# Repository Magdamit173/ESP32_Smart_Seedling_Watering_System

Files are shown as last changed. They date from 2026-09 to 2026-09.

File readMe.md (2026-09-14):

# ESP32-Based Smart Seedling Watering System with Automated Environmental Control

A low-cost, locally controlled seedling watering prototype designed to reduce repetitive manual watering while combining embedded programming, environmental sensing, real-time scheduling, relay/solenoid control, fluid delivery, and mechanical fabrication.

> **Project:** Midterm Project #1  
> **Course:** Microprocessors, Microcontroller Systems and Design  
> **Author:** Rovic B. Magdamit  
> **Institution:** University of Caloocan City – College of Engineering

## Overview

The system automates watering for a small seedling tray using an **ESP32-C3** as the central controller. It uses a **DHT22/AM2302** for temperature and relative-humidity monitoring and a **DS3231 RTC** for the time reference required by daily watering schedules.

A phone or laptop connects directly to the ESP32's local Wi-Fi access point and opens the controller's web interface. No cloud service or external router is required.

The final prototype uses a gravity-fed water path:

```text
~10-L Reservoir
      │
      ▼
 Clear Tubing
      │
      ▼
 Solenoid Valve
      │
      ▼
 Water Outlet
      │
      ▼
 Seedling Tray
```

The electrical/control path is:

```text
DHT22 ───────────────┐
                     │
DS3231 ──────────────┤
                     ▼
                ESP32-C3
                     │
              Control Logic
                     │
                     ▼
              Transistor/Relay
                     │
                     ▼
               Solenoid Valve
```

## Main Features

- Daily scheduled watering using the DS3231 RTC
- Configurable temperature and relative-humidity rules
- Optional second environmental condition using **AND** or **OR**
- Configurable persistence period before an environmental rule can trigger watering
- Cooldown period to reduce repeated environmental triggering
- Wireless manual watering
- Wireless force-stop watering
- Hard software watering limit of **30 minutes**
- Non-blocking `millis()` timing for watering duration, sensor polling, persistence, and cooldown
- Local Wi-Fi SoftAP + HTTP web interface
- Configuration stored in ESP32 non-volatile storage using `Preferences`
- Connected devices can retrieve the ESP32's stored schedules and environmental rules
- DS3231 retains the time reference when the ESP32 is unpowered
- Relay and solenoid inductive-load protection using flyback diodes

## Hardware

### Controller

| Component | Function |
|---|---|
| ESP32-C3 SuperMini | Main controller, Wi-Fi access point, web server |
| DHT22 / AM2302 | Temperature and relative-humidity sensing |
| DS3231 RTC | Time-of-day reference for scheduled watering |
| SRD-05VDC-SL-C relay | Electrical isolation/switching for watering actuator |
| PN2222A transistor drivers | Relay/actuator driver stage |
| LM7805 | 5 V regulation |
| Flyback diodes | Inductive-load protection |
| LED indicator | Visual status indication |
| DC barrel jack | External power input |
| Terminal blocks / headers | Wiring connections |

### Watering and Structure

- Approximately 10-L plastic reservoir
- Clear tubing
- DC solenoid valve
- Seedling tray
- Blue PVC pipe
- PVC elbow and tee fittings
- Nylon rope for reservoir/outlet support
- Clear acrylic electronics enclosure
- Acrylic adhesive

## ESP32-C3 Pin Assignment

| ESP32-C3 Pin | Assignment | Function |
|---|---|---|
| GPIO4 | `DHT_PIN` | DHT22 / AM2302 data |
| GPIO5 | `WATER_PIN` | Relay/transistor watering control |
| GPIO6 | `RTC_SDA` | DS3231 SDA |
| GPIO7 | `RTC_SCL` | DS3231 SCL |
| I2C `0x68` | DS3231 | RTC device address |
| `192.168.4.1` | Wi-Fi AP | Local HTTP configuration interface |

## Power Arrangement

The prototype uses a **12 V DC input** before regulation.

The controller uses a regulated **5 V rail** for the low-voltage electronics and compatible actuator/control circuitry.

The solenoid is controlled through the relay/transistor stage rather than directly from an ESP32 GPIO.

> The external adapter's current rating is a maximum available capacity; the connected load draws the current required by the circuit.

## Software Architecture

The firmware runs as a continuously serviced control loop.

The major tasks are:

1. Service the local HTTP server.
2. Read the DHT22 at the configured sensor interval.
3. Read the DS3231 for calendar/time-of-day information.
4. Evaluate scheduled watering events.
5. Evaluate environmental rules.
6. Control the relay/solenoid watering output.
7. Enforce watering duration and safety limits.
8. Save/retrieve controller configuration through non-volatile storage.

### Non-Blocking Timing

Watering is intentionally not implemented as a long `delay()` operation.

When watering begins, the firmware records the starting value of `millis()` and checks elapsed time on later loop iterations.

The same approach is used for:

- watering duration
- environmental persistence
- cooldown
- sensor polling

This allows the ESP32 to continue servicing the web interface and other controller tasks while watering is active.

## Scheduling and Environmental Rules

### Scheduled Watering

A scheduled event contains:

- time of day
- watering duration
- enable state

The DS3231 provides the calendar-time reference used to determine when a daily event is due.

### Environmental Watering

An environmental rule can use:

- temperature or relative humidity
- comparison operator
- threshold
- optional second condition
- `AND` / `OR` logic
- persistence period
- watering duration
- cooldown

For example, a rule can conceptually be configured as:

```text
IF temperature > threshold
AND the condition remains true for the persistence period
THEN water for the configured duration
AND wait for the cooldown before another trigger
```

The system does **not** claim that one watering amount is correct for every plant. Watering duration is configurable because plant type, tray geometry, substrate, age, temperature, and humidity can change actual water requirements.

## Local Web Interface

The ESP32 creates its own local Wi-Fi network:

```text
SSID: ESP32_Smart_Seedling_Waterer
IP:   192.168.4.1
```

A connected phone or laptop can use the browser interface for:

- schedule configuration
- temperature/humidity rule configuration
- automation control
- manual watering
- force stop
- controller status monitoring
- retrieving the stored configuration

The ESP32's **non-volatile configuration is the shared source of truth**, while browser `localStorage` acts as a local editing copy. This allows a newly connected device to retrieve the current configuration instead of depending on the settings stored only in one browser.

## RTC Operation

The DS3231 is used specifically for **time-of-day scheduling**.

The distinction between the DS3231 and `millis()` is important:

- `millis()` measures elapsed time only while the ESP32 is running.
- The DS3231 provides the calendar/time reference for daily schedules and retains the clock when the ESP32 is unpowered.

The RTC was verified during development using an I2C scanner and a focused RTClib test. The DS3231 appeared at:

```text
0x68
```

The other observed I2C device at `0x57` was present during the scanner test but was not used as the RTC device.

## Fluid-System Design

The final prototype is **gravity-fed** and does not use a separate pump.

The water surface is elevated above the valve/outlet, creating hydrostatic head:

\[
P = \rho g h
\]

where:

- \(P\) = hydrostatic pressure contribution
- \(\rho\) = water density
- \(g\) = gravitational acceleration
- \(h\) = vertical water head

As an illustrative reference, a **9-inch vertical water head**:

```text
9 in = 0.2286 m
```

corresponds to approximately:

```text
2.24 kPa
≈ 0.33 psi
```

This is a reference calculation based on elevation difference, not a measured pressure value for every reservoir fill condition.

Actual flow depends on:

- reservoir water level
- valve elevation
- tubing resistance
- valve orifice
- fitting losses
- outlet geometry

The selected low/zero-differential-pressure solenoid arrangement is therefore appropriate for a gravity-fed concept where a conventional pressure-driven valve may not operate correctly at very low available pressure.

## Structural Design

The physical support structure uses blue PVC pipe with elbow and tee fittings.

The main square members are approximately:

```text
9 in × 9 in
```

with additional short and diagonal members used for support and bracing.

The structure supports:

- the reservoir
- the watering outlet
- the tubing
- the seedling tray area

The reservoir was based on an approximately **10-L container**. Water alone has an approximate mass of:

```text
10 kg
```

and an approximate weight of:

```text
W = mg
  ≈ 98.1 N
```

The nylon rope attachment points distribute the hanging load into the PVC support structure. Actual rope tension depends on attachment geometry and load distribution, so the prototype is considered a demonstration structure rather than a rated lifting frame.

The PVC joints were assembled without additional sealant because the fitted prototype was sufficiently rigid for the intended demonstration.

## Electronics Enclosure

The controller electronics were assembled inside a small clear acrylic enclosure.

The enclosure accommodates:

- controller board
- relay/driver circuitry
- wiring
- power input
- manual controls
- actuator connections

The enclosure was fabricated as a practical prototype rather than a production enclosure. Visible adhesive and cable management reflect the iterative construction process.

## Development and Iteration

The project was developed through repeated testing and redesign rather than a single build sequence.

### 1. Initial Mechanical Concept

The earliest concept involved transporting a seedling tray through a watering zone using a conveyor.

The concept was eventually abandoned because the added requirements for:

- motor control
- guides
- entry/exit sensing
- mechanical timing
- additional fabrication

made the system unnecessarily complex for the available prototype resources.

The final design retained the programmable watering concept but changed to a stationary seedling watering structure.

### 2. Wireless Communication

Bluetooth Low Energy was attempted first.

The prototype repeatedly experienced connection/disconnection behavior and browser GATT service retrieval failures. The communication design was therefore changed to **ESP32 SoftAP Wi-Fi + HTTP**, which preserved local wireless operation while simplifying browser interaction.

### 3. RTC Debugging

The main program initially reported the DS3231 as not detected even though the eventual hardware connection was correct.

An I2C scanner identified:

```text
0x57
0x68
```

A focused RTClib test then detected the DS3231 at `0x68` and returned a readable time.

### 4. Configuration Synchronization

The web interface initially did not consistently reconstruct schedules and environmental rules across different connected devices.

The final approach stores the configuration on the ESP32 using non-volatile storage. The browser maintains a local editing copy, while the ESP32 remains the authoritative stored configuration.

## Safety and Reliability

The prototype includes several protections and reliability measures:

- 30-minute maximum watering duration
- dedicated force-stop command
- relay coil flyback protection
- solenoid inductive-load flyback protection
- transistor drivers between control logic and actuator circuitry
- independent DS3231 time reference
- non-blocking elapsed-time logic
- non-volatile configuration storage
- low-pressure gravity-fed watering arrangement

The system is intended as a low-cost educational prototype, not a certified agricultural or load-bearing product.

## Estimated Project Cost

The documented/estimated project cost is approximately:

```text
₱1,235
```

This includes recorded purchase prices, approximate prices for unpriced components, an estimated **₱30** for three 2-pin terminal blocks, and a **₱300 miscellaneous/catch-up allowance** for solder, small parts, and other unpriced consumables.

The figure represents best-effort prototype spending rather than an exact manufacturing cost for a production unit.

## Project Status

The completed prototype demonstrates integrated operation of:

- embedded control
- environmental sensing
- real-time scheduling
- local wireless configuration
- relay/solenoid actuation
- gravity-fed water delivery
- PVC structural support
- acrylic electronics enclosure

The strongest result of the project is the integration of these subsystems into one functional prototype.

## Repository Contents

The repository contains the complete implementation and supporting project resources.

The full firmware and project files are maintained here so the complete source does not need to be reproduced in the printed project documentation.

## Author

**Rovic B. Magdamit**  
ECE - 3A  
University of Caloocan City  
College of Engineering  
Electronics Engineering Department

## Project Title

**ESP32-Based Smart Seedling Watering System with Automated Environmental Control**

## License

No software license has been specified yet. Unless a license is added to this repository, the project should be treated as the author's project work and reused according to the repository owner's permission.

## AI-Assisted Development

AI tools were used as development assistants for brainstorming, debugging, code review, technical writing, and documentation. Final implementation, hardware construction, testing, and project decisions were performed and verified by the author.

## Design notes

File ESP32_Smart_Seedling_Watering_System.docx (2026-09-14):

University of Caloocan City

College of Engineering

Electronics Engineering Department

Microprocessors, Microcontroller Systems and Design

Midterm Project # 1

ESP32-Based Smart Seedling Watering System with Automated Environmental Control

Submitted by:

Magdamit, Rovic B.

ECE - 3A

Submitted to:

Engr. Glenda C. Morales

September 15, 2026

Abstract

This project presents the design and development of an ESP32-based smart seedling watering system intended to reduce the repetitive manual work involved in watering young plants. The completed prototype combines an ESP32-C3 controller, a DHT22/AM2302 temperature and relative-humidity sensor, a DS3231 real-time clock, a relay and transistor driver stage, a DC solenoid valve, a regulated power section, a small seedling tray, tubing, and a manually assembled PVC support structure. The controller can execute daily watering schedules and configurable temperature/humidity rules through a locally hosted wireless web interface. Environmental rules can require a condition to remain true for a defined persistence period before watering and can apply a cooldown to reduce repeated triggering. Manual watering and a force-stop command are also provided. Timing for watering duration, sensor intervals, persistence, and cooldown is implemented with non-blocking millis()-based logic so the main control loop can continue servicing the web server and sensors. The DS3231 provides the time-of-day reference used for schedules and retains the clock when the controller itself is unpowered. Configuration is stored on the ESP32 using non-volatile storage so connected devices can retrieve the current schedule and rule settings. The final prototype evolved through several iterations, including an abandoned conveyor concept, a Bluetooth Low Energy communication attempt, and debugging of the RTC interface before the final Wi-Fi and RTC arrangement was stabilized. The resulting system demonstrates an integrated application of embedded programming, electronics, sensing, relay control, fluid delivery, and mechanical fabrication within a low-cost prototype.

Keywords: ESP32-C3, seedling watering, DHT22, DS3231 RTC, solenoid valve

Introduction

Background

Watering young seedlings is simple in principle but repetitive in practice. Seedling trays often require small and repeated watering events, and the consistency of those events can depend on whether a person is available to perform them at the correct time. The project began from this practical problem and from the observation that repeatedly watering plants can become tiring and easy to postpone. The design goal therefore shifted from simply opening a valve with a microcontroller to building a small, programmable controller that can repeat watering actions consistently and can be adjusted without rewiring the hardware.

The finished prototype uses the ESP32-C3 as the central controller. A DHT22/AM2302 provides temperature and relative-humidity measurements, while a DS3231 real-time clock supplies the time reference needed for daily schedules. The controller drives a solenoid valve through a transistor-and-relay interface. A local Wi-Fi access point and web interface allow a phone or laptop to configure schedules, environmental rules, manual watering duration, and automation state without requiring a cloud service or an external router. The ESP32 stores configuration in non-volatile storage so that the controller can retain its operating settings across restarts.

Project Requirement

The Microprocessors, Microcontroller Systems and Design project requirement was to create a project that is smart, helpful, marketable, and useful using an ESP32, relay, and solenoid valve. The present system addresses that requirement by combining a programmable embedded controller with a practical water-delivery application for seedlings. Rather than claiming a universal watering amount for every plant, the system emphasizes repeatable and user-configurable watering. This approach is consistent with the design notes developed during the project, which emphasize controlled watering and calibration rather than claiming that the controller can perfectly determine plant thirst.

Problem Statement

The project addresses the need for a compact and low-cost watering system that can perform repetitive seedling watering actions without requiring a person to activate the valve every time. The system must provide a dependable time reference for scheduled watering, sense environmental conditions, permit wireless configuration, control a solenoid valve safely, and allow manual intervention. It must also continue its timing and control logic without using long blocking delays that would prevent the controller from responding to other tasks.

Objectives

- To design and assemble an ESP32-C3-based controller capable of driving a DC solenoid valve through a relay and transistor driver stage.
- To implement daily watering schedules using a DS3231 real-time clock and user-defined watering durations.
- To implement temperature/humidity rules with configurable thresholds, persistence periods, optional second conditions, and cooldown periods.
- To provide a local Wi-Fi web interface for configuration, monitoring, manual watering, force stopping, and retrieval of the current controller configuration.
- To build a compact physical watering structure using PVC, tubing, a reservoir, a seedling tray, and an acrylic electronics enclosure.
- To evaluate the completed prototype through functional tests of sensing, timekeeping, wireless communication, configuration persistence, valve control, and physical water delivery.

Significance

The project demonstrates how a microcontroller can bridge several practical engineering disciplines in one system. Electrical design is required for power regulation, relay control, transistor driving, and inductive-load protection. Embedded programming is required for scheduling, sensor sampling, non-blocking timing, and web communication. Instrumentation is represented by environmental sensing and the RTC. Fluid handling is introduced through the reservoir, tubing, solenoid valve, and outlet. Finally, mechanical fabrication is required to support the reservoir and route the watering hardware. This integration makes the prototype relevant not only as a classroom microcontroller exercise but also as a small example of an automated nursery or seedling-management subsystem. The final system also required fluid-mechanics reasoning and structural consideration: gravity from the elevated reservoir provides the driving head for water movement, while the PVC frame and rope supports carry the reservoir load. This makes the project an integrated electromechanical and fluid-delivery system rather than an electronics-only prototype.

Methodology

Materials and Equipment

- ESP32-C3 SuperMini development board
- DHT22 / AM2302 temperature and relative-humidity sensor
- DS3231 real-time clock module
- 5 V relay (SRD-05VDC-SL-C) and PN2222A transistor drivers
- DC solenoid valve and clear fluid tubing
- 12 V DC adapter, LM7805 regulator, capacitors, resistors, flyback diodes, LED indicator, DC barrel jack, and terminal connections
- Custom PCB/perfboard implementation and connecting headers
- Blue PVC pipes and assorted elbow/tee fittings for the support frame
- Nylon rope for reservoir/support attachment
- Approximately 10-L plastic reservoir container and seedling tray
- Clear acrylic sheet for the electronics enclosure and acrylic adhesive
- Computer/phone for local web configuration, Arduino IDE, KiCad, and a digital multimeter

System Architecture

The final architecture places the ESP32-C3 at the center of the system. The DHT22 feeds environmental data to the controller, while the DS3231 supplies the time-of-day reference. User devices communicate with the ESP32 through its local Wi-Fi access point and HTTP interface. The controller decides when watering should occur and drives the relay/driver path connected to the solenoid valve. The electrical power section provides the external DC input and the regulated logic rail. The architecture therefore separates sensing, decision-making, actuation, and user configuration while keeping the entire system local.

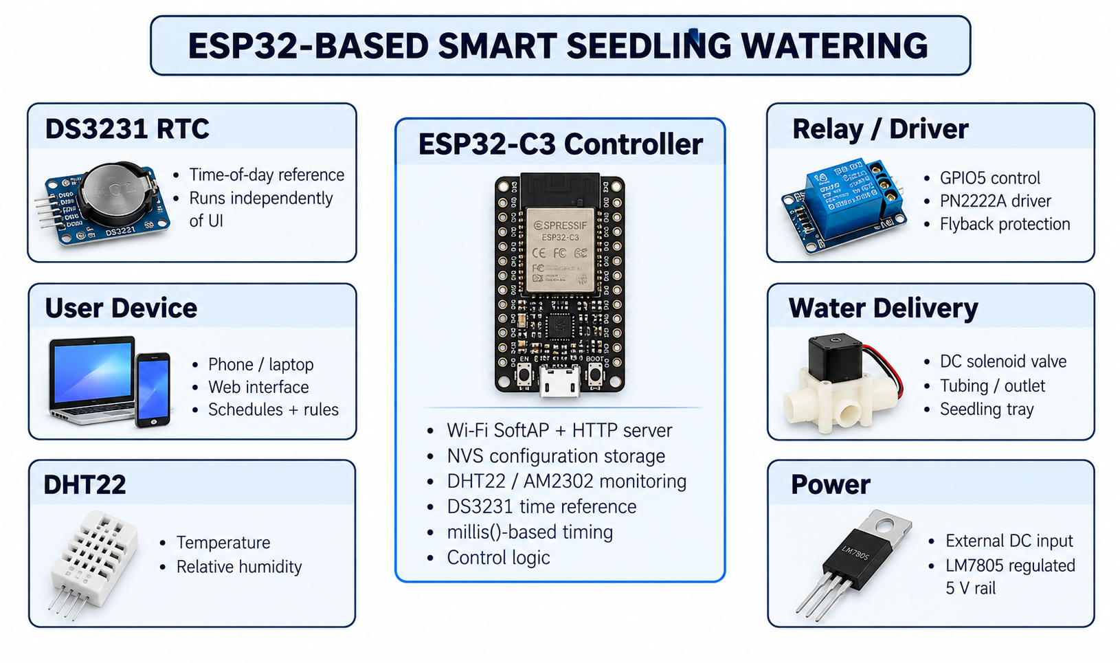
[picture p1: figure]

Figure 1. Functional architecture of the completed ESP32-based smart seedling watering system.

Electrical Design and PCB

The controller board was designed in KiCad and organized into functional groups for the relay and manual-switch path, power regulation, indicator circuit, and ESP32/RTC/DHT22 connections. The supplied PCB design uses a 1.6 mm board thickness and an outline of approximately 83.8 mm by 51.8 mm (8.38 cm by 5.18 cm) according to the KiCad board file. The ESP32-C3 uses GPIO5 for the watering control signal, GPIO6 for I2C SDA, GPIO7 for I2C SCL, and GPIO4 for the DHT22 data line. The relay coil uses a transistor driver and flyback diode, while the solenoid path includes a separate flyback diode for inductive-load protection. The relay and manual-water input share the actuation stage so that the same valve can be controlled by either the software command or the physical manual control.

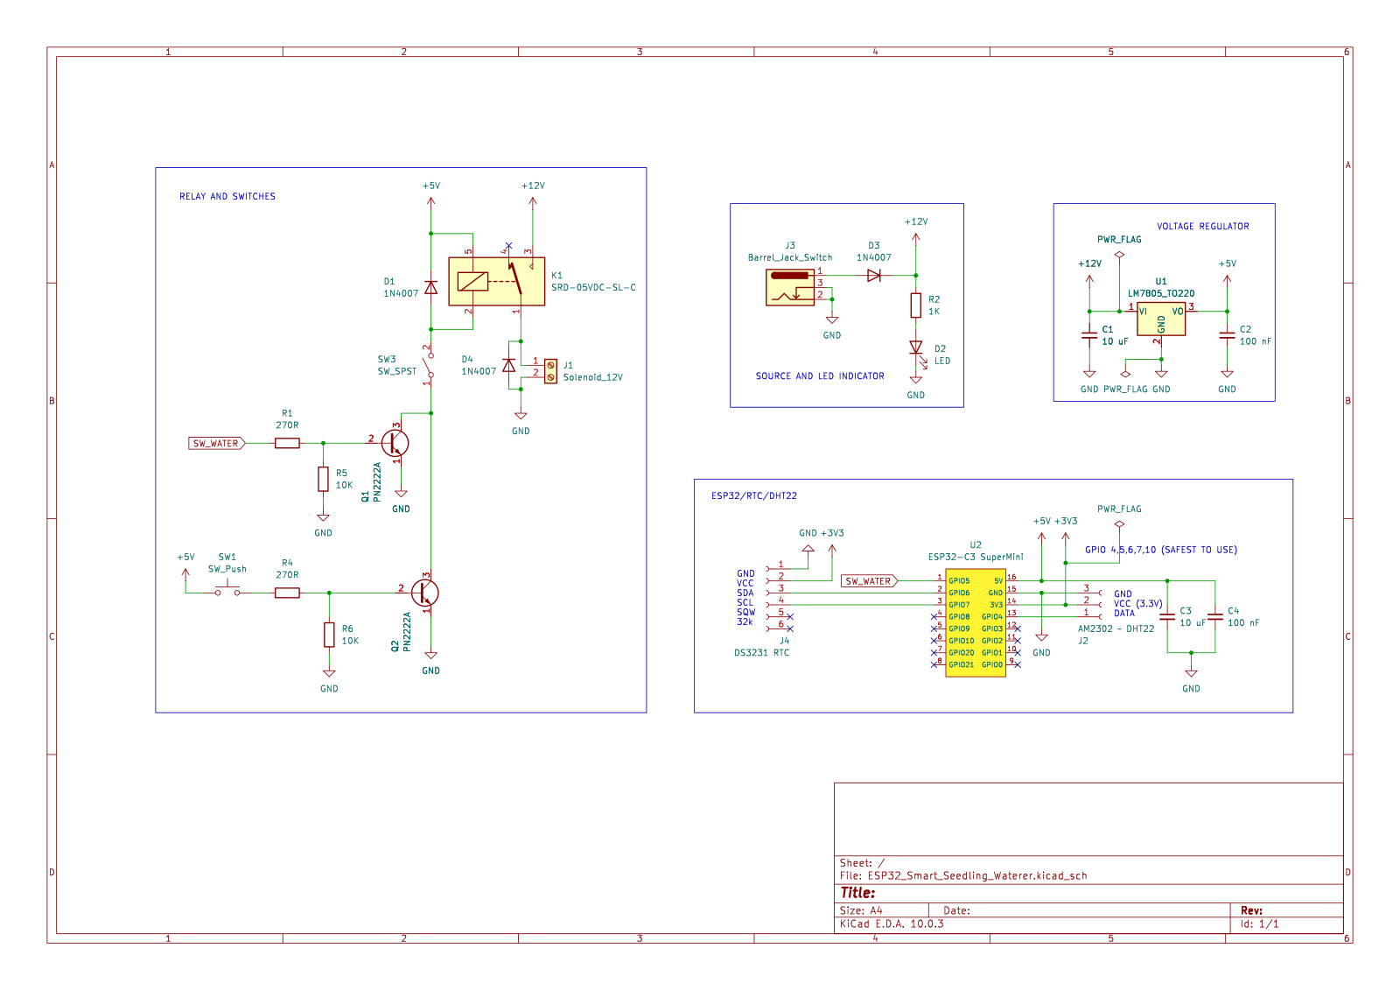
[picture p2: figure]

Figure 2. KiCad schematic/layout overview showing the relay, manual switch, power regulation, ESP32-C3, DHT22, and DS3231 connections.

Pin Assignment

Device / Function | ESP32-C3 connection | Purpose
DHT22 / AM2302 data | GPIO4 | Temperature and relative-humidity input
Water control | GPIO5 | Drives transistor/relay watering path
DS3231 SDA | GPIO6 | I2C data
DS3231 SCL | GPIO7 | I2C clock
Power | 5 V regulated rail / GND | Controller and peripherals
External supply | 12 V DC input | System power source before regulation

Software and Control Logic

The firmware is written for the ESP32-C3 using the Arduino environment. The main loop repeatedly services the HTTP server, samples the DHT22 at a defined interval, updates watering duration, and evaluates automation rules. Watering is deliberately implemented without long blocking delays. When watering begins, the firmware stores the start time using millis() and checks elapsed time on later loop iterations. The same non-blocking approach is used for environmental persistence, cooldown timing, and sensor polling. This allows the controller to continue responding to network requests while the solenoid is active.

The DS3231 is used for actual time-of-day scheduling. The browser can synchronize the current local time to the RTC through the local interface, after which the ESP32 reads the RTC independently of the phone. The DS3231 is also checked for a power-loss indication at startup. This is distinct from the volatile runtime timing performed with millis(): millis() measures elapsed intervals while the controller is running, whereas the DS3231 supplies calendar time for daily schedules and retains its time reference when the ESP32 is unpowered.

Configuration is maintained as a structured controller configuration containing automation state, manual duration, and up to ten events. Events can be scheduled watering events or environmental rules. Environmental rules can contain a first sensor condition, an optional second condition joined by AND or OR, a persistence interval, a watering duration, and a cooldown. The configuration is stored in ESP32 non-volatile storage using the Preferences library. The local browser also maintains a local copy for editing, while the ESP32 remains the authoritative stored configuration when devices connect.

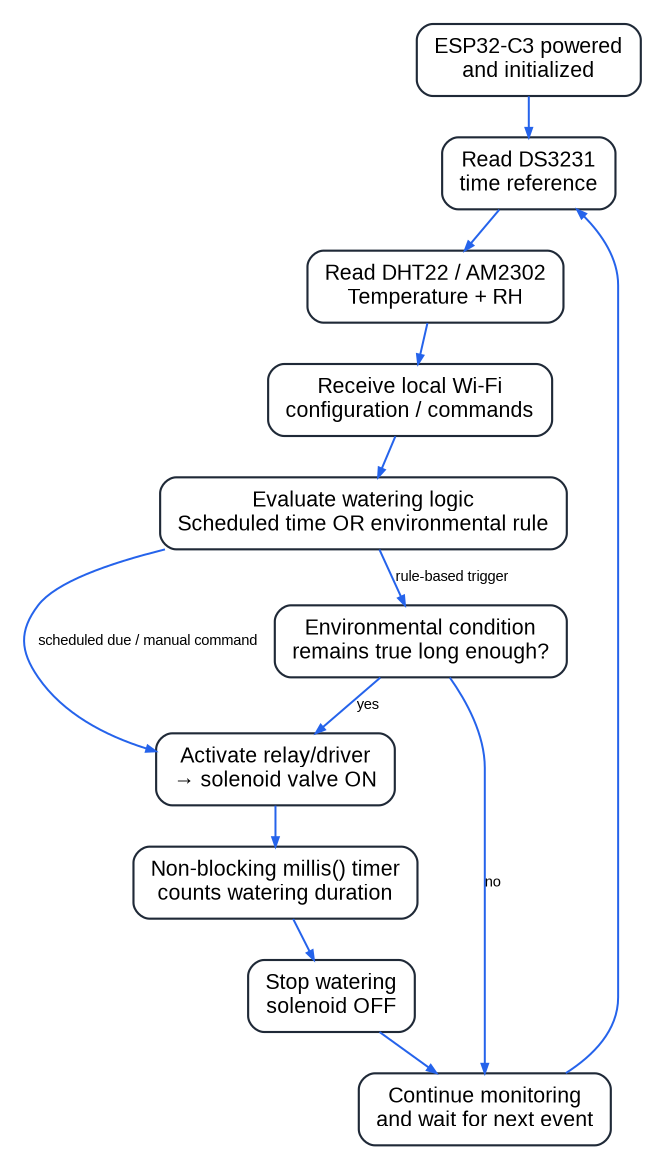
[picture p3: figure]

Figure 3. Control flow of the final firmware, showing RTC timekeeping, environmental sensing, rule evaluation, non-blocking watering timing, and return to monitoring.

Mechanical Construction

The physical watering frame was fabricated from blue PVC pipe with assorted elbow and tee fittings. The main square sections are approximately 9 inches per side, with additional short members, tees, and diagonal members used to support the reservoir, watering outlet, and seedling area. The repeated closed rectangular members provide a stable load path, while the additional bracing helps reduce sway when the reservoir is filled. The joints were assembled without additional sealant because the fitted prototype was already sufficiently rigid for the intended demonstration. Nylon rope was used at multiple attachment points to suspend and stabilize the reservoir and outlet assembly. For structural interpretation, the full reservoir load is approximately 10 kg of water before the bottle and fittings are added, corresponding to about 98 N of gravitational load. The actual tension in each rope segment depends on its attachment angle and how the load is distributed, so the prototype was treated as a low-cost demonstration structure rather than a rated lifting frame.

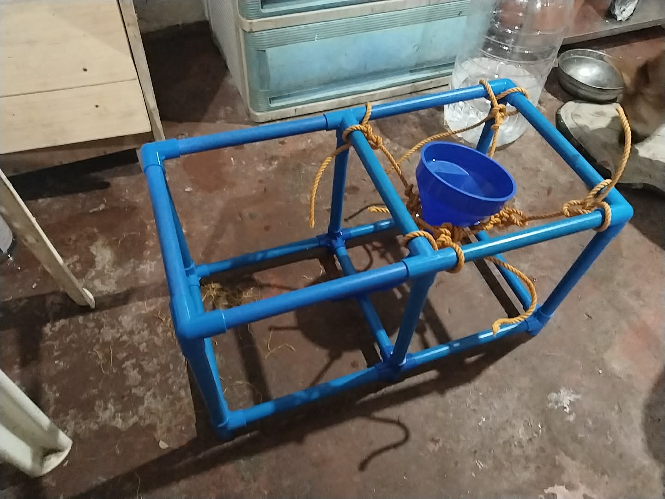
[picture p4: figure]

Figure 4. PVC structural frame and manually assembled watering outlet support.

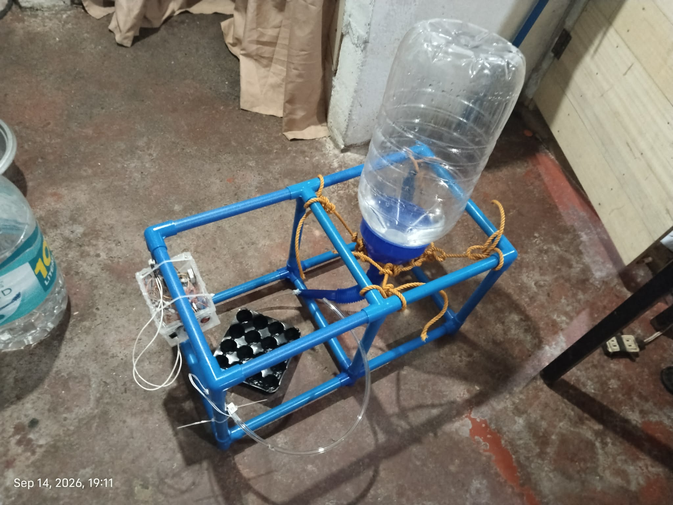
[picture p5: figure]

Figure 5. Final physical prototype with reservoir, watering frame, tubing, seedling tray, and controller enclosure.

Electronics Enclosure

The controller electronics were housed in a small clear acrylic enclosure cut and bonded during the prototype stage. The enclosure was designed to fit the controller board, wiring, power input, manual controls, relay, and valve connections while keeping the electronics visible for demonstration and troubleshooting. The prototype used adhesive bonding and improvised wire management with cable ties. The enclosure is functional rather than cosmetic, and the visible adhesive and exposed wiring reflect the rapid iterative construction process used to complete the project within the available time.

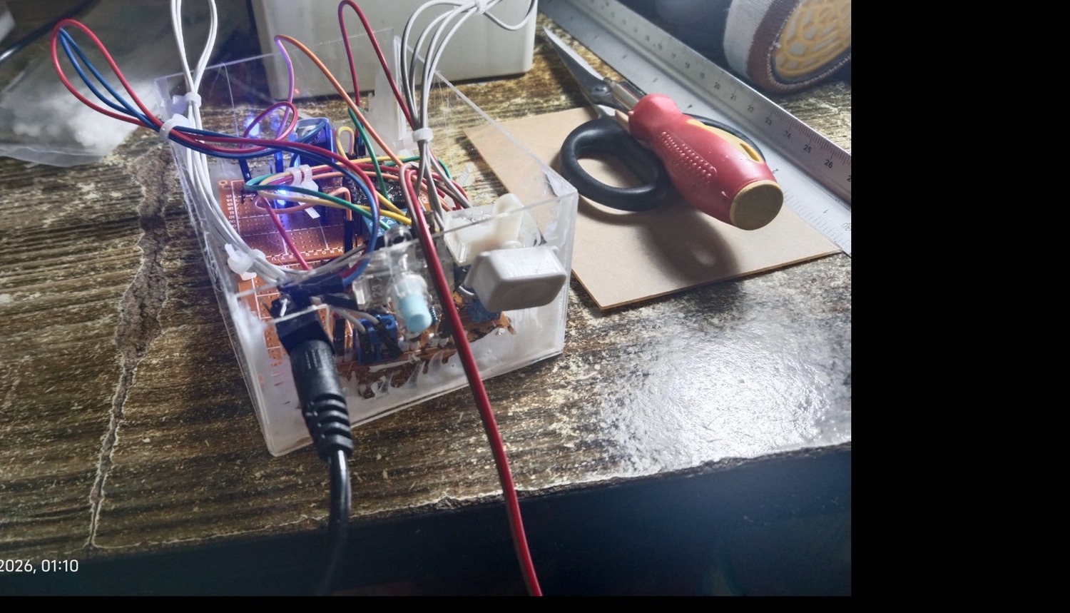
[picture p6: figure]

Figure 6. Acrylic enclosure containing the controller electronics, relay, wiring, and external connectors.

Procedure

1. Planning and requirement definition: The project was framed around a repetitive seedling-watering problem and the requirement to use an ESP32, relay, and solenoid valve. The initial concept included a conveyor or watering tunnel, but this was later reduced to a stationary tray system to keep the final prototype achievable with available materials and time.

2. Electrical prototyping: The ESP32-C3, DHT22, relay/driver circuit, manual control, regulator, and solenoid path were tested individually before being combined. Flyback protection and regulated power were incorporated into the controller design.

3. RTC integration: The DS3231 was connected through GPIO6/GPIO7. An initial detection problem was traced with an I2C scanner, which eventually confirmed devices at 0x57 and 0x68. A focused RTClib test then detected the DS3231 and returned a readable time, confirming that the hardware and I2C bus were operating correctly.

4. Wireless interface development: Bluetooth Low Energy was attempted first, but repeated connection and GATT service retrieval failures led to a Wi-Fi SoftAP design. The final controller creates a local Wi-Fi network and serves the web interface at 192.168.4.1 without requiring an external router.

5. Configuration and persistence development: The browser interface was built to edit schedules and environmental rules. The design was revised so the ESP32 non-volatile configuration is the shared source of truth; a newly connected device retrieves the stored configuration and reconstructs the same schedule and rule interface.

6. Physical construction: The PVC frame, reservoir support, tubing path, watering outlet, acrylic enclosure, and controller wiring were assembled and adjusted repeatedly until the final integrated layout could be demonstrated.

7. Functional verification: The completed system was checked for environmental sensing, RTC communication, local Wi-Fi operation, watering command execution, timed shutoff, manual control, force-stop behavior, configuration persistence, and physical water delivery.

Results and Discussion

System Integration Results

The final prototype successfully brought together the electrical controller, environmental sensor, RTC, wireless interface, relay and solenoid actuation path, water delivery hardware, and physical frame. The system is represented in the final photographs as a complete assembly rather than as separate bench tests. The controller enclosure contains the active electronics, while the external structure provides the reservoir support and gravity-fed water path. The 10-L reservoir provides a practical demonstration-scale water supply, and the approximately 9-inch frame geometry keeps the assembly compact while creating the elevation needed for gravity-assisted flow. This integration is the main result of the project because the required ESP32, relay, and solenoid operate as parts of one physical application.

Functional Verification

Test item | Observed result | Assessment
ESP32-C3 startup | Serial startup completed and local AP address reported as 192.168.4.1. | Pass
DHT22 / AM2302 | Temperature and relative-humidity values were read and responded to environmental changes during testing. | Pass
DS3231 I2C communication | I2C scan detected 0x57 and 0x68; focused RTClib test detected the DS3231 and returned a readable time. | Pass after wiring/initialization debugging
Scheduled watering | Firmware checks RTC time and triggers configured daily events without blocking the main loop. | Implemented / integrated
Environmental rules | Temperature/humidity thresholds, persistence, optional second condition, and cooldown are represented in the configuration and control logic. | Implemented / integrated
Manual watering | Web interface provides a user-defined watering duration. | Implemented / integrated
Force stop | Web command immediately stops watering through the same actuation path. | Implemented / integrated
Configuration persistence | Schedules and environmental rules are stored through Preferences/NVS and returned through the configuration endpoint. | Implemented / integrated
Non-blocking timing | Water duration, persistence, cooldown, and sensor interval use millis()-based elapsed-time checks. | Pass
Physical water delivery | Reservoir, tubing, valve, outlet, and seedling tray were assembled into the final frame. | Pass for prototype demonstration

Iterations and Failure Analysis

The project required repeated trial and error rather than a single build sequence. The earliest mechanical concept involved transporting a seedling tray through a watering zone with a conveyor. This concept was consistent with a miniature nursery tunnel, but its motor, guide, entry/exit sensing, and mechanical timing requirements increased the fabrication burden. The design was therefore simplified into a stationary seedling watering system while retaining the programmable watering and wireless-control ideas.

Communication development also required iteration. Bluetooth Low Energy initially appeared attractive because it would avoid dependence on a router, but the prototype repeatedly entered connect/disconnect cycles and browser GATT service retrieval failed. The design was changed to ESP32 SoftAP Wi-Fi, which fit the same local-device concept while making the browser interface easier to operate. The final firmware uses the ESP32 as the access point and web server.

The DS3231 also generated an early false-negative result. The main firmware first reported the RTC as not detected even though the wiring was ultimately correct. A dedicated I2C scanner identified 0x68, and a smaller RTClib sketch then detected the DS3231 and read its time. The issue therefore came from the initialization path in the larger program rather than from a failed RTC module. The final firmware explicitly starts the I2C bus on GPIO6 and GPIO7 and checks the 0x68 device before initializing RTClib.

The browser configuration interface required another round of debugging because schedules and environmental rules were initially not consistently repopulated across connected devices. The final design treats the ESP32 non-volatile configuration as the master copy, with the browser localStorage acting as a local editing copy. This change makes the configuration available to any device that connects to the ESP32 rather than tying the visible schedule to one browser alone.

Environmental and Fluid-System Considerations

The prototype intentionally avoids claiming that one fixed watering volume is correct for every seedling. Water demand depends on plant type, tray geometry, substrate, age, temperature, and humidity. The control strategy instead treats valve-open duration as a configurable quantity. In the physical prototype, water moves from an elevated reservoir through clear tubing and the solenoid valve to the outlet over the seedling tray, with no separate pump used in the final arrangement. The elevation of the water surface above the valve provides gravitational pressure (hydrostatic head), while losses in the tubing, fittings, and outlet reduce the pressure available at the discharge. For water, the pressure contribution from elevation can be approximated by P = rho g h. As a reference, a 9-inch vertical water head (0.2286 m) corresponds to approximately 2.24 kPa or 0.33 psi of hydrostatic gauge pressure. The actual head in the prototype changes with reservoir fill level and the exact relative height of the valve and outlet. Because the valve used in the prototype is intended for low/zero differential-pressure operation, the gravity-fed arrangement is practical without a pump; zero-differential solenoid valves are specifically designed to open without requiring a positive pressure differential (Parker Hannifin Corporation, 2025; SMC Corporation, 2025). The final flow rate still depends on head, tubing resistance, valve orifice, fittings, and outlet geometry, so future calibration should measure delivered water volume for several valve-open durations rather than assuming a universal flow rate.

Physical-System Reference Calculations

Parameter | Expression / Basis | Reference Result
Water mass in 10-L reservoir | m ≈ 10 L × 1 kg/L | ≈ 10 kg
Reservoir water weight | W = mg | ≈ 98.1 N
9-in vertical water head | h = 9 in = 0.2286 m; P = rho g h | ≈ 2.24 kPa ≈ 0.33 psi
Frame dimensions | Main square members ≈ 9 in per side | Prototype reference dimension

Note: the 9-inch head calculation is an illustrative reference based on elevation difference, not a measured pressure value for every reservoir fill condition. Rope tension was not directly measured.

Safety and Reliability Features

- The watering duration is constrained by a 30-minute software maximum.
- A dedicated force-stop command immediately turns the watering output off.
- Flyback diodes are included for the relay coil and solenoid inductive load.
- Transistor drivers separate the microcontroller output from the higher-current relay/actuator path.
- The DS3231 supplies an independent time reference instead of relying entirely on volatile ESP32 runtime time.
- Watering and rule timing use millis()-based elapsed-time checks rather than long blocking delays.
- Controller configuration is retained in ESP32 non-volatile storage so a power cycle does not automatically erase the saved schedules and rules.

The reservoir support was also kept mechanically simple: multiple rope attachment points share the hanging load, while the PVC frame provides distributed support through its rectangular and braced members. Because neither the rope grade nor structural joints were laboratory load-rated, the result is documented as a prototype support arrangement rather than a certified load-bearing structure.

Estimated Project Cost

The following estimate combines the recorded purchase prices with the approximate prices supplied during documentation. Reused female headers are treated as having no additional purchase cost. The three 2-pin terminal blocks are estimated at about PHP 10 each, while soldering lead, minor consumables, and other unpriced catch-up items are covered by a PHP 300 miscellaneous allowance. Several prototype parts were purchased in quantities larger than the final build required, so this table reflects documented project spending rather than an exact manufacturing cost per finished unit.

Item | Qty. | Unit / assumed cost (PHP) | Estimated total (PHP)
Nylon rope | 1 | 80 | 80
Blue PVC pipe/fittings order | 1 | 139 | 139
Acrylic enclosure material | 2 | ~40 | 80
12 V DC adapter | 1 | 43 | 43
DC solenoid valve | 1 | 71 | 71
Seedling tray | 2 | ~4.50 | 9
Clear tubing | 1 | 19 | 19
DHT22 / AM2302 module | 1 | 72 | 72
DS3231 RTC module | 1 | ~30 | 30
Relay SRD-05VDC-SL-C | 3 | ~19.67 | 59
ESP32-C3 SuperMini | 1 | 136 | 136
PCB pieces | 2 | 10 | 20
Acrylic glue sticks | 3 | 10 | 30
DC barrel jack | 1 | 10 | 10
Switches | 2 | 20 | 40
1N4007 diodes | 3 | 1 | 3
LED | 1 | 5 | 5
Resistors | 5 | 1 | 5
PN2222A transistors | 3 | 3 | 9
LM7805 regulator | 1 | 25 | 25
Capacitors | 4 | 5 | 20
2-pin terminal blocks | 3 | ~10 | 30
Miscellaneous / solder / reused small parts allowance | 1 | 300 | 300

Estimated project cost: PHP 1,235 (best-effort estimate; includes a PHP 300 miscellaneous/catch-up allowance and ~PHP 30 estimated terminal-block cost).

Conclusion

The ESP32-Based Smart Seedling Watering System with Automated Environmental Control met the central Microprocessors, Microcontroller Systems and Design requirement by combining an ESP32 controller with a relay and solenoid valve into a practical and programmable seedling-watering application. The completed prototype includes environmental sensing through the DHT22, calendar-time scheduling through the DS3231, local wireless configuration through the ESP32-C3 SoftAP and HTTP interface, non-volatile configuration storage, relay-based actuation, and a physical water-delivery structure fabricated from low-cost materials.

The project also demonstrated that integration was more demanding than any individual circuit. Electrical behavior, embedded timing, sensor behavior, real-time clock communication, water flow, structural support, enclosure fabrication, and user-interface persistence all had to work together. Several iterations were necessary before the final arrangement was stable, including simplification of the original conveyor concept, replacement of BLE with local Wi-Fi, and debugging of DS3231 initialization and configuration synchronization. These failures were useful engineering steps because they led to a simpler and more maintainable final system.

The final prototype should be considered a compact proof-of-concept rather than a production agricultural machine. Its strongest contribution is repeatable, configurable control of a small seedling watering process at low cost. Future refinement can improve the mechanical frame, enclosure finish, water distribution uniformity, reservoir mounting, calibration of delivered volume, and long-term environmental protection. Even in its current form, the system demonstrates a complete embedded engineering workflow from requirement definition and circuit design to fabrication, programming, debugging, and physical integration.

References

Adafruit Industries (2026). DHT11, DHT22 and AM2302 Sensors. https://learn.adafruit.com/dht

Adafruit Industries (2026). RTClib: RTC_DS3231 class reference. https://adafruit.github.io/RTClib/html/class_r_t_c___d_s3231.html

Espressif Systems (2026). Arduino-ESP32 Wi-Fi API. https://docs.espressif.com/projects/arduino-esp32/en/latest/api/wifi.html

Espressif Systems (2026). Preferences: Non-volatile storage for Arduino-ESP32. https://docs.espressif.com/projects/arduino-esp32/en/latest/tutorials/preferences.html

Espressif Systems (2026). SoftAP example and captive portal concepts. https://github.com/espressif/arduino-esp32/blob/master/libraries/DNSServer/examples/CaptivePortal/CaptivePortal.ino

OpenStax (2022). College Physics 2e: Fluids. https://openstax.org/details/books/college-physics-2e

Parker Hannifin Corporation (2025). General Purpose Solenoid Valves: Direct-lift models with zero-pressure opening capability. https://www.parker.com/content/dam/Parker-com/Literature/Fluid-Control-Division/Static-Files/fcd-fl0911/general_purpose_solenoid_valves_cat_fcdfl0911.pdf

SMC Corporation (2025). VXZ Series: 2 Port Solenoid Valve, Zero Pressure Differential Operation. https://content.smcetech.com/pdf/VXZ_EU.pdf

ASHRAE (2025). Chapter 22: Pipe and Tube Design. https://handbook.ashrae.org/Handbooks/F25/IP/F25_Ch22/F25_Ch22_ip.aspx

OpenStax (2020). Physics: Tension and Newton’s laws of motion. https://openstax.org/books/physics/pages/4-4-newtons-third-law-of-motion

AI-Assisted Development Disclosure
Artificial intelligence tools were used as development assistants during the project for brainstorming, software debugging, code review, documentation refinement, and troubleshooting. The final hardware assembly, testing, design decisions, implementation, and validation were performed by the author. AI-generated suggestions were reviewed, adapted, and tested against the actual prototype.

Appendix A. Final Firmware Pin Map

The following mapping is taken from the supplied final ESP32-C3 firmware. The current code defines the DHT22 on GPIO4, the watering control on GPIO5, and the DS3231 I2C interface on GPIO6 and GPIO7.

Pin / Interface | Assignment | Function
GPIO4 | DHT_PIN | DHT22 / AM2302 data
GPIO5 | WATER_PIN | Relay/transistor watering control
GPIO6 | RTC_SDA | DS3231 SDA
GPIO7 | RTC_SCL | DS3231 SCL
I2C address | 0x68 | DS3231 device address observed during debugging
Wi-Fi AP | 192.168.4.1 | Local HTTP configuration interface

Appendix B. Representative Firmware Logic

The firmware uses millis() - based elapsed-time checks to control watering duration, sensor polling, environmental persistence, and cooldown without long blocking delays. The complete source is maintained in the project repository referenced in Appendix C.

# Appendix C. Complete Project Repository

The complete ESP32-C3 firmware, project resources, and supporting implementation files are available in the project repository: https://github.com/magdamit173/esp32_Smart_Seedling_Watering_System

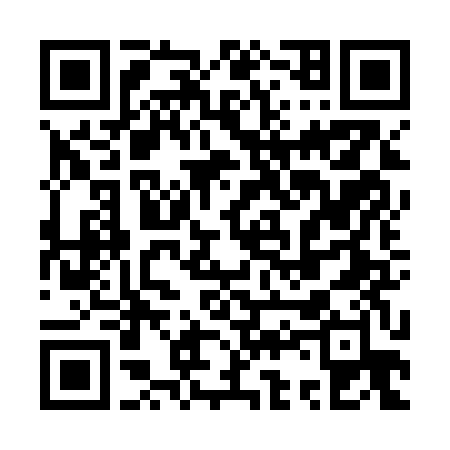
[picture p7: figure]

Figure 7. QR code linking to the ESP32 Smart Seedling Watering System project repository.

Repository URL: https://github.com/magdamit173/esp32_Smart_Seedling_Watering_System

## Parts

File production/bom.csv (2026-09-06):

Designator | Footprint | Quantity | Value | LCSC Part #
C1, C3 | C_Disc_D5.0mm_W2.5mm_P5.00mm | 2 | 10 uF
C2, C4 | C_Disc_D5.0mm_W2.5mm_P5.00mm | 2 | 100 nF
D1, D3, D4 | D_DO-41_SOD81_P10.16mm_Horizontal | 3 | 1N4007
D2 | LED_D5.0mm | 1 | LED
J1 | TerminalBlock_Phoenix_MKDS-1,5-2_1x02_P5.00mm_Horizontal | 1 | Solenoid_12V
J2 | PinSocket_1x03_P2.54mm_Vertical | 1 | AM2302 ~ DHT22
J3 | BarrelJack_GCT_DCJ200-10-A_Horizontal | 1 | Barrel_Jack_Switch
J4 | PinSocket_1x06_P2.54mm_Vertical | 1 | DS3231 RTC
K1 | Relay_SPDT_SANYOU_SRD_Series_Form_C | 1 | SRD-05VDC-SL-C
Q1, Q2 | TO-92_HandSolder | 2 | PN2222A
R1, R4 | R_Axial_DIN0207_L6.3mm_D2.5mm_P10.16mm_Horizontal | 2 | 270R
R2 | R_Axial_DIN0207_L6.3mm_D2.5mm_P10.16mm_Horizontal | 1 | 1K
R5, R6 | R_Axial_DIN0207_L6.3mm_D2.5mm_P10.16mm_Horizontal | 2 | 10K
SW1 | TerminalBlock_Phoenix_MKDS-1,5-2_1x02_P5.00mm_Horizontal | 1 | SW_Push
SW3 | TerminalBlock_Phoenix_MKDS-1,5-2_1x02_P5.00mm_Horizontal | 1 | SW_SPST
U1 | TO-220-3_Horizontal_TabDown | 1 | LM7805_TO220
U2 | ESP32-C3 SuperMini | 1 | ESP32-C3 SuperMini

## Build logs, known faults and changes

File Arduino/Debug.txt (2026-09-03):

#include <DHT.h>

#define SW_WATER 5
#define DHT_PIN 4
#define DHT_TYPE DHT22

DHT dht(DHT_PIN, DHT_TYPE);

void setup() {
  Serial.begin(115200);

  pinMode(SW_WATER, OUTPUT);
  digitalWrite(SW_WATER, LOW);

  dht.begin();

  Serial.println("ESP32-C3 Smart Seedling Watering");
  Serial.println("System started");
}

void loop() {
  // Blink LED
  digitalWrite(SW_WATER, HIGH);
  delay(1000);

  digitalWrite(SW_WATER, LOW);
  delay(1000);

  // Read DHT22
  float humidity = dht.readHumidity();
  float temperature = dht.readTemperature();

  if (isnan(humidity) || isnan(temperature)) {
    Serial.println("DHT22: Failed to read");
  } else {
    Serial.print("Relative Humidity: ");
    Serial.print(humidity);
    Serial.println(" %");

    Serial.print("Temperature: ");
    Serial.print(temperature);
    Serial.println(" °C");
  }

  Serial.println("--------------------");
}

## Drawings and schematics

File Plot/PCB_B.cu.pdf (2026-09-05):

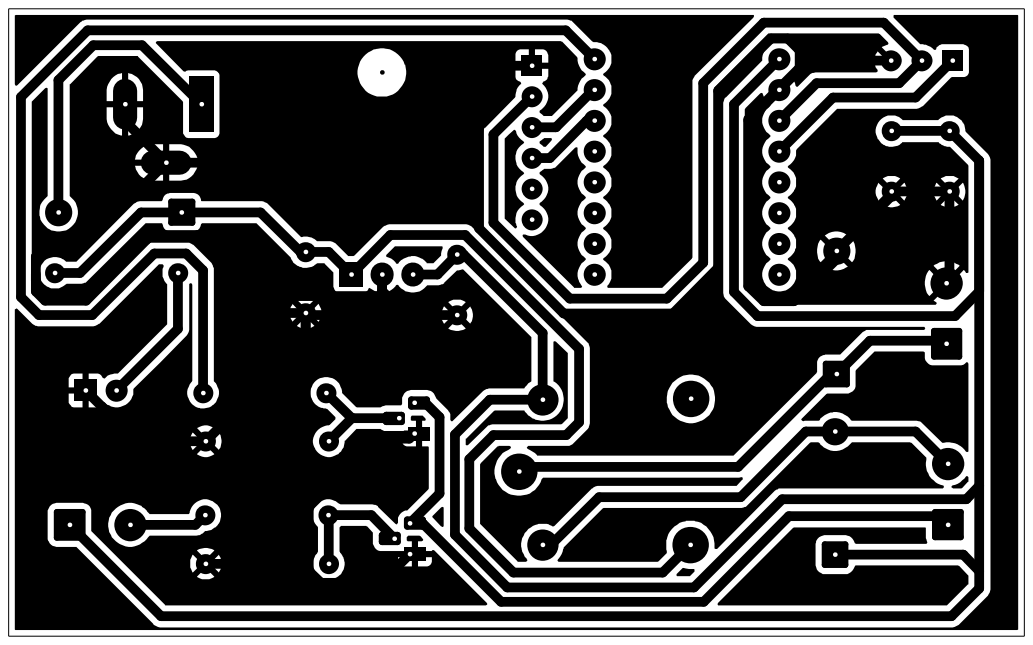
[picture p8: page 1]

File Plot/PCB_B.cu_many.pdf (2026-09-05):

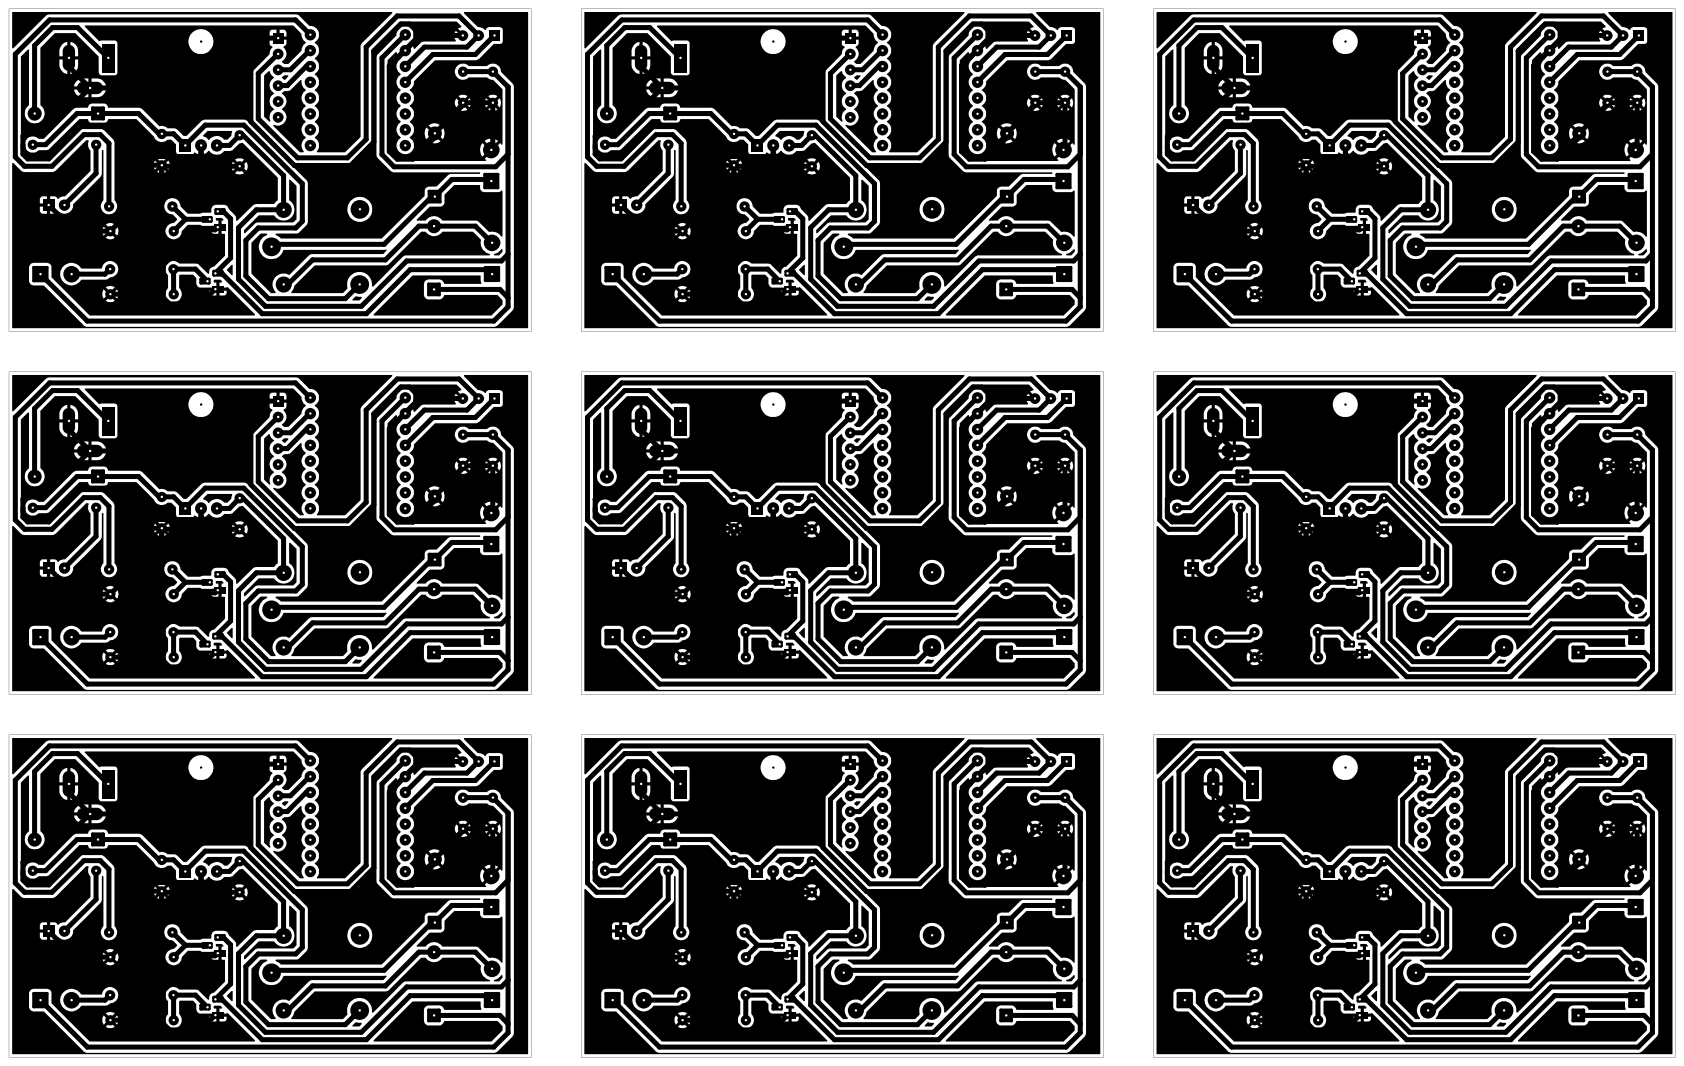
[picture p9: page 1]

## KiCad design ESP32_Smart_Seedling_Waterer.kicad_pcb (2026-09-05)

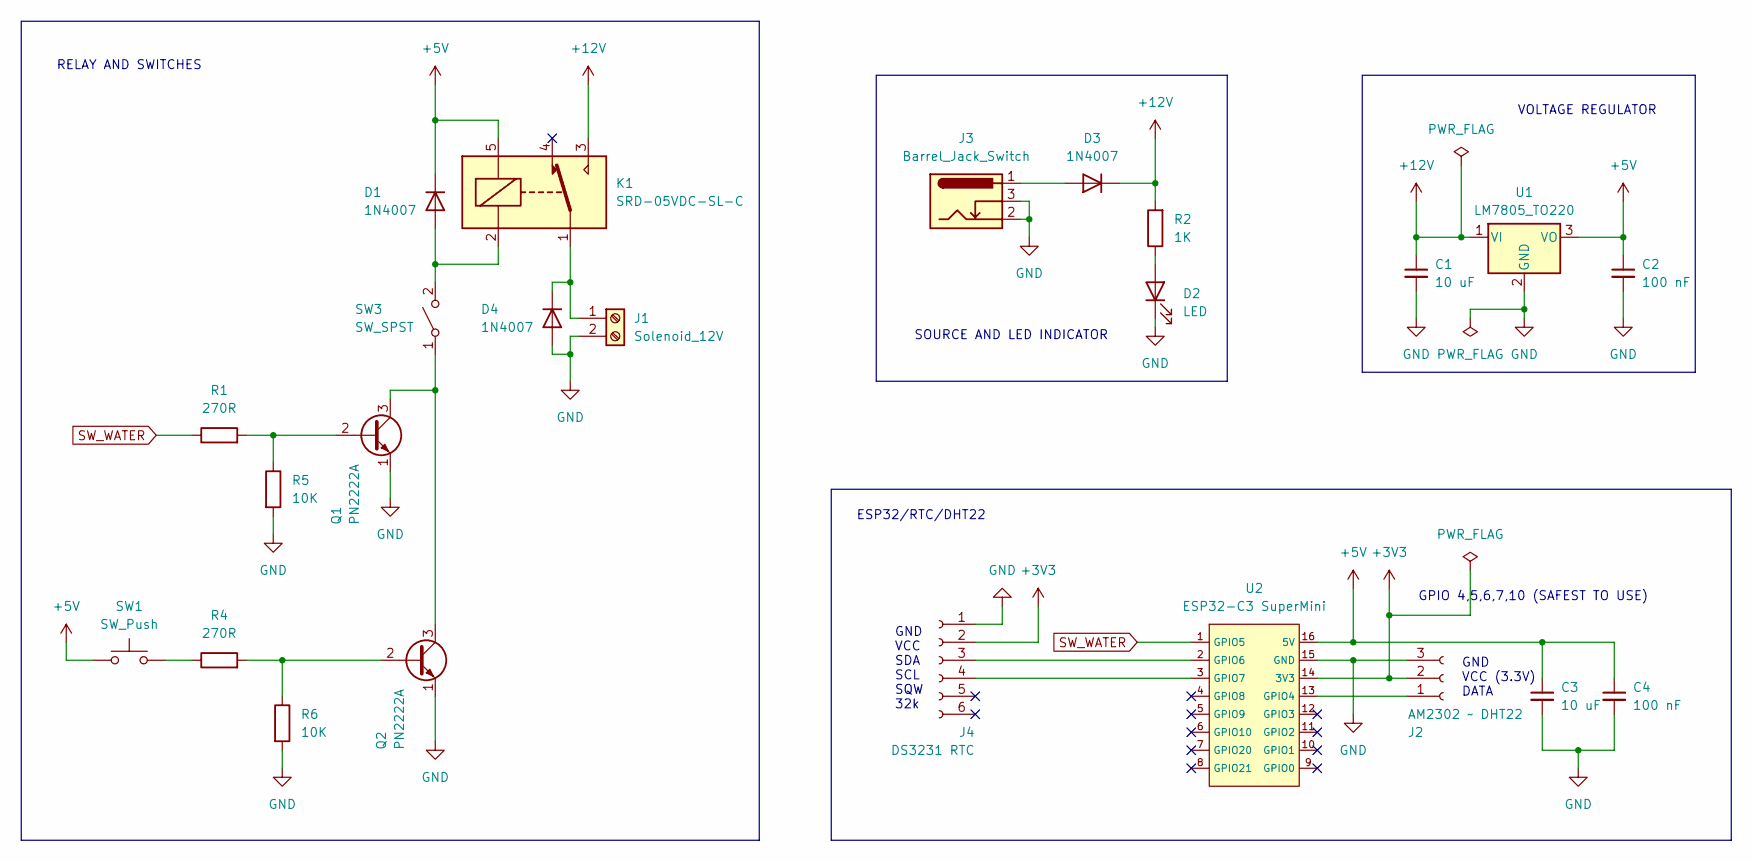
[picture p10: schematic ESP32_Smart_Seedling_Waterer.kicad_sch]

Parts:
C1, C3: 10 uF; C_Disc_D5.0mm_W2.5mm_P5.00mm
C2, C4: 100 nF; C_Disc_D5.0mm_W2.5mm_P5.00mm
D1, D3, D4: 1N4007; D_DO-41_SOD81_P10.16mm_Horizontal
D2: LED; LED_D5.0mm
J1: Solenoid_12V; TerminalBlock_Phoenix_MKDS-1,5-2_1x02_P5.00mm_Horizontal
J2: AM2302 ~ DHT22; PinSocket_1x03_P2.54mm_Vertical
J3: Barrel_Jack_Switch; BarrelJack_GCT_DCJ200-10-A_Horizontal
J4: DS3231 RTC; PinSocket_1x06_P2.54mm_Vertical
K1: SRD-05VDC-SL-C; Relay_SPDT_SANYOU_SRD_Series_Form_C
Q1, Q2: PN2222A; TO-92_HandSolder
R1, R4: 270R; R_Axial_DIN0207_L6.3mm_D2.5mm_P10.16mm_Horizontal
R2: 1K; R_Axial_DIN0207_L6.3mm_D2.5mm_P10.16mm_Horizontal
R5, R6: 10K; R_Axial_DIN0207_L6.3mm_D2.5mm_P10.16mm_Horizontal
SW1: SW_Push; TerminalBlock_Phoenix_MKDS-1,5-2_1x02_P5.00mm_Horizontal
SW3: SW_SPST; TerminalBlock_Phoenix_MKDS-1,5-2_1x02_P5.00mm_Horizontal
U1: LM7805_TO220; TO-220-3_Horizontal_TabDown
U2: ESP32-C3 SuperMini

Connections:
+3V3: J2.2, J4.2, U2.14 (3V3)
+5V: C2.1, C3.1, C4.1, D1.1 (K), K1.5, SW1.1, U1.3 (VO), U2.16 (5V)
+12V: C1.1, D3.1 (K), K1.3, R2.2, U1.1 (VI)
GND: C1.2, C2.2, C3.2, C4.2, D2.1 (K), D4.2 (A), J1.2, J2.3, J3.2, J3.3, J4.1, Q1.1 (E), Q2.1 (E), R5.2, R6.2, U1.2 (GND), U2.15 (GND)
unnamed: D1.2 (A), K1.2, SW3.2 (B)
unnamed: D2.2 (A), R2.1
unnamed: D3.2 (A), J3.1
unnamed: D4.1 (K), J1.1, K1.1
unnamed: J2.1, U2.13 (GPIO4)
unnamed: J4.3, U2.2 (GPIO6)
unnamed: J4.4, U2.3 (GPIO7)
unnamed: Q1.2 (B), R1.2, R5.1
unnamed: Q1.3 (C), Q2.3 (C), SW3.1 (A)
unnamed: Q2.2 (B), R4.2, R6.1
unnamed: R4.1, SW1.2
SW_WATER: R1.1, U2.1 (GPIO5)

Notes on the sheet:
VOLTAGE REGULATOR
SOURCE AND LED INDICATOR
RELAY AND SWITCHES
GND VCC SDA SCL SQW 32k
GPIO 4,5,6,7,10 (SAFEST TO USE)
GND VCC (3.3V) DATA
ESP32/RTC/DHT22

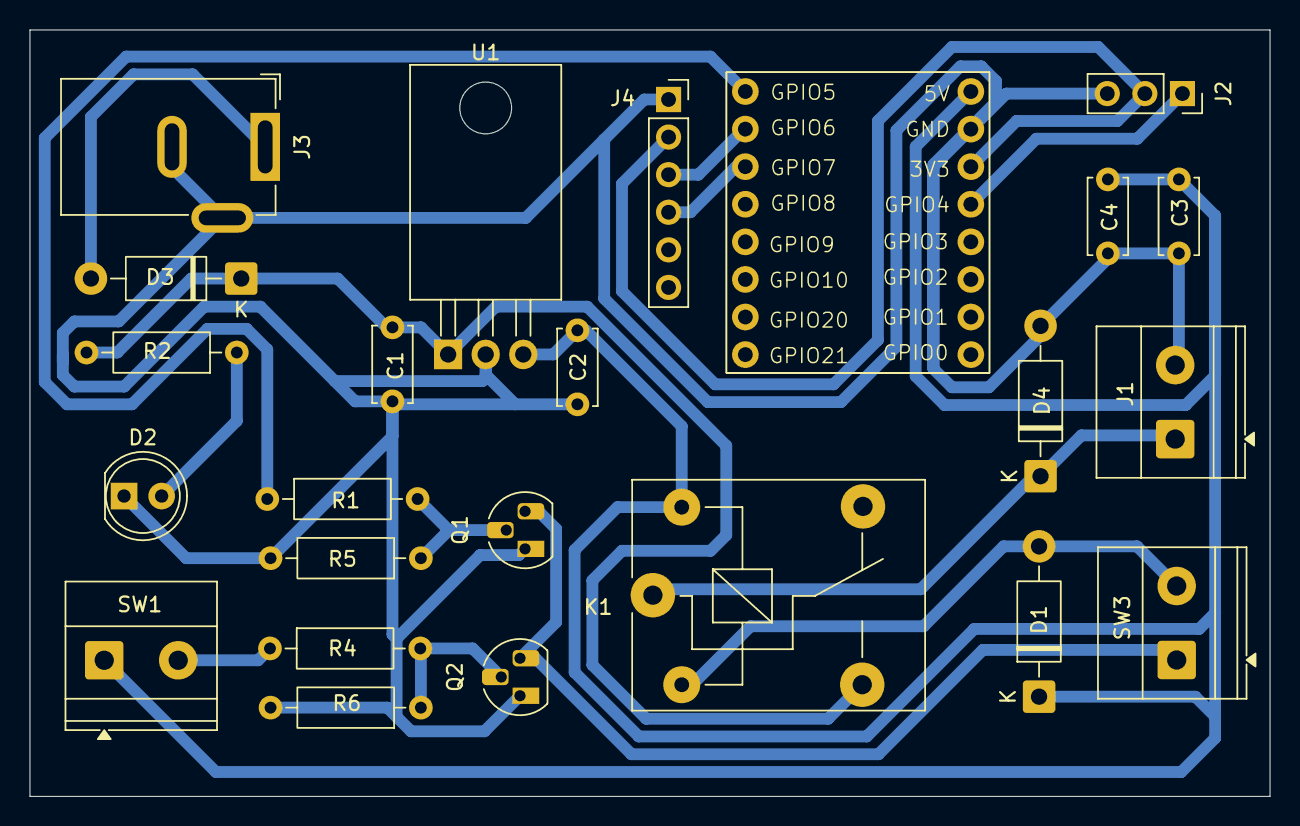
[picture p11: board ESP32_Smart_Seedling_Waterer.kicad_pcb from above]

Board: 2 copper layers, 83.8 x 51.8 mm, 24 parts (0 on the bottom side), 16 nets.

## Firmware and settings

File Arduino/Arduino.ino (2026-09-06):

#include <Arduino.h>
#include <WiFi.h>
#include <WebServer.h>
#include <DHT.h>
#include <Preferences.h>
#include <sys/time.h>
#include <time.h>
#include <Wire.h>
#include <RTClib.h>

#define DHT_PIN 4
#define WATER_PIN 5
#define DHT_TYPE DHT22
#define RTC_SDA 6
#define RTC_SCL 7

const char* WIFI_SSID = "ESP32_Smart_Seedling_Waterer";
const uint8_t MAX_EVENTS = 10;
const uint32_t MAX_DURATION_SEC = 1800;
const uint32_t SENSOR_INTERVAL_MS = 10000;
const uint32_t CONFIG_MAGIC = 0x53454544;

WebServer server(80);
DHT dht(DHT_PIN, DHT_TYPE);
Preferences prefs;
RTC_DS3231 rtc;
bool rtcAvailable = false;

struct ConditionConfig {
    bool enabled;
    uint8_t sensor;
    uint8_t op;
    float threshold;
};

struct EventConfig {
    bool enabled;
    uint8_t type;
    char time[6];
    uint32_t durationSec;
    ConditionConfig first;
    ConditionConfig second;
    bool secondEnabled;
    uint8_t logic;
    uint32_t persistenceSec;
    uint32_t cooldownSec;
};

struct DeviceConfig {
    uint32_t magic;
    bool automationEnabled;
    uint32_t manualDurationSec;
    uint8_t eventCount;
    EventConfig events[MAX_EVENTS];
};

DeviceConfig config;

int64_t rtcLastScheduleDay[MAX_EVENTS];
int64_t rtcConditionSince[MAX_EVENTS];
int64_t rtcLastConditionTrigger[MAX_EVENTS];
bool rtcStateInitialized = false;

float currentTemperature = NAN;
float currentHumidity = NAN;
bool waterState = false;
uint32_t waterStartMs = 0;
uint32_t waterDurationMs = 0;
String lastReason = "None";
uint32_t lastSensorReadMs = 0;

const char INDEX_HTML[] PROGMEM = R"rawliteral(
<!DOCTYPE html>
<html lang="en">
<head>
    <meta charset="UTF-8">
    <meta name="viewport" content="width=device-width, initial-scale=1.0">
    <title>ESP32 Smart Seedling Waterer</title>
    <link rel="stylesheet" href="style.css">
</head>
<body>
    <header class="site-header">
        <div class="header-content">
            <div>
                <h1 class="site-title">ESP32 Smart Seedling Waterer</h1>
                <p class="site-subtitle">Rule based watering controller</p>
            </div>
            <div class="connection-status">
                <span class="connection-dot" id="connection-dot" data-state="offline"></span>
                <span id="connection-label">Offline</span>
            </div>
        </div>
    </header>

    <main class="app">
        <section class="toolbar panel">
            <div class="device-controls">
                <label class="field-label" for="device-address">ESP32 Address</label>
                <input class="text-input" id="device-address" value="http://192.168.4.1" autocomplete="off" spellcheck="false">
                <button class="button button-primary" type="button" data-action="connect">Connect</button>
                <button class="button button-secondary" type="button" data-action="disconnect">Disconnect</button>
            </div>
            <div class="program-controls">
                <button class="button button-success" type="button" data-action="run">Enable Automation</button>
                <button class="button button-danger" type="button" data-action="stop">Stop Automation</button>
                <button class="button button-primary" type="button" data-action="save">Save to ESP32</button>
            </div>
        </section>

        <section class="status-grid">
            <article class="panel status-card">
                <span class="status-card-label">Device Time</span>
                <strong class="status-card-value" id="status-time">--:--:--</strong>
                <span class="status-card-note" id="status-clock">Clock not synced</span>
            </article>
            <article class="panel status-card">
                <span class="status-card-label">Temperature</span>
                <strong class="status-card-value" id="status-temperature">--</strong>
                <span class="status-card-note">DHT22 / AM2302</span>
            </article>
            <article class="panel status-card">
                <span class="status-card-label">Humidity</span>
                <strong class="status-card-value" id="status-humidity">--</strong>
                <span class="status-card-note">Relative humidity</span>
            </article>
            <article class="panel status-card">
                <span class="status-card-label">SW_WATER</span>
                <strong class="status-card-value" id="status-water">OFF</strong>
                <span class="status-card-note" id="status-water-time">Ready</span>
            </article>
        </section>

        <section class="content-grid">
            <div class="main-column">
                        <section class="panel section-card">
                    <div class="section-heading">
                        <div>
                            <h2>Scheduled Watering</h2>
                            <p>Water every day at a selected time for a selected duration.</p>
                        </div>
                        <button class="button button-primary" type="button" data-action="add-schedule">Add Time</button>
                    </div>
                    <div class="event-list" id="schedule-list"></div>
                    <div class="empty-message" id="schedule-empty">No scheduled watering events.</div>
                </section>

                <section class="panel section-card">
                    <div class="section-heading">
                        <div>
                            <h2>Temperature / Humidity Rules</h2>
                            <p>Water when a condition stays true for a required time. Cooldown prevents repeated watering.</p>
                        </div>
                        <button class="button button-primary" type="button" data-action="add-condition">Add Rule</button>
                    </div>
                    <div class="event-list" id="condition-list"></div>
                    <div class="empty-message" id="condition-empty">No environmental watering rules.</div>
                </section>
            </div>

            <aside class="side-column">
                <section class="panel section-card">
                    <div class="section-heading compact">
                        <div>
                            <h2>Manual Watering</h2>
                            <p>Wireless manual watering from this page.</p>
                        </div>
                    </div>
                    <label class="field-label" for="manual-duration">Duration</label>
                    <div class="inline-field">
                        <input class="text-input" id="manual-duration" type="number" min="1" max="1800" value="30">
                        <select class="select-input" id="manual-unit">
                            <option value="seconds">seconds</option>
                            <option value="minutes" selected>minutes</option>
                        </select>
                    </div>
                    <button class="button button-success button-large" type="button" data-action="manual-water">WATER NOW</button>
                    <button class="button button-danger button-large" type="button" data-action="force-stop">FORCE STOP WATERING</button>
                    <p class="safety-note">Hard limit: <strong>30 minutes</strong> maximum watering time.</p>
                </section>

                <section class="panel section-card">
                    <div class="section-heading compact">
                        <div>
                            <h2>Device</h2>
                            <p>Local controller status.</p>
                        </div>
                    </div>
                    <div class="device-detail"><span>Automation</span><strong id="device-automation">OFF</strong></div>
                    <div class="device-detail"><span>Last Action</span><strong id="device-reason">None</strong></div>
                    <div class="device-detail"><span>Remaining</span><strong id="device-remaining">0 s</strong></div>
                    <div class="device-detail"><span>Max Duration</span><strong>30 min</strong></div>
                </section>

                <section class="panel section-card">
                    <div class="section-heading compact">
                        <div>
                            <h2>Log</h2>
                        </div>
                        <button class="button button-secondary" type="button" data-action="clear-log">Clear</button>
                    </div>
                    <div class="log" id="log"></div>
                </section>
            </aside>
        </section>
    </main>

    <footer class="site-footer">ESP32 Smart Seedling Waterer</footer>
    <script src="app.js" defer></script>
</body>
</html>

)rawliteral";

const char STYLE_CSS[] PROGMEM = R"rawliteral(
* {
    box-sizing: border-box;
}

:root {
    font-family: Arial, Helvetica, sans-serif;
    color: #172033;
    background: #eef2f7;
}

body {
    margin: 0;
    min-height: 100vh;
}

button,
input,
select {
    font: inherit;
}

button {
    cursor: pointer;
}

.site-header {
    background: #111827;
    color: #fff;
    border-bottom: 4px solid #2563eb;
}

.header-content,
.app,
.site-footer {
    width: min(1500px, 96%);
    margin: 0 auto;
}

.header-content {
    padding: 18px 0;
    display: flex;
    align-items: center;
    justify-content: space-between;
    gap: 20px;
}

.site-title {
    margin: 0 0 6px;
    font-size: 25px;
}

.site-subtitle {
    margin: 0;
    color: #cbd5e1;
    font-size: 13px;
}

.connection-status {
    display: flex;
    align-items: center;
    gap: 8px;
    font-size: 14px;
    font-weight: 700;
}

.connection-dot {
    width: 10px;
    height: 10px;
    border-radius: 50%;
    background: #ef4444;
}

.connection-dot[data-state="online"] {
    background: #22c55e;
}

.app {
    margin-top: 18px;
    margin-bottom: 30px;
}

.panel {
    background: #fff;
    border: 1px solid #d7dde7;
    border-radius: 10px;
    box-shadow: 0 2px 10px rgba(15, 23, 42, 0.05);
}

.toolbar {
    padding: 12px;
    display: flex;
    justify-content: space-between;
    align-items: center;
    gap: 12px;
    flex-wrap: wrap;
}

.device-controls,
.program-controls,
.inline-field,
.section-heading,
.switch-row,
.device-detail {
    display: flex;
    align-items: center;
}

.device-controls,
.program-controls {
    gap: 7px;
    flex-wrap: wrap;
}

.section-heading {
    justify-content: space-between;
    gap: 12px;
}

.section-heading.compact {
    align-items: flex-start;
}

.field-label {
    font-size: 12px;
    font-weight: 700;
    color: #475569;
}

.text-input,
.select-input {
    width: 100%;
    padding: 8px 10px;
    border: 1px solid #cbd5e1;
    border-radius: 6px;
    background: #fff;
    color: #172033;
}

#device-address {
    width: 190px;
}

.button {
    border: 0;
    border-radius: 6px;
    padding: 8px 12px;
    color: #fff;
}

.button:hover {
    filter: brightness(0.94);
}

.button-primary {
    background: #2563eb;
}

.button-secondary {
    background: #64748b;
}

.button-success {
    background: #16a34a;
}

.button-danger {
    background: #dc2626;
}

.button-large {
    width: 100%;
    padding: 13px 12px;
    margin-top: 12px;
    font-weight: 800;
}

.status-grid {
    margin-top: 15px;
    display: grid;
    grid-template-columns: repeat(4, minmax(0, 1fr));
    gap: 12px;
}

.status-card {
    padding: 16px;
}

.status-card-label,
.status-card-note {
    display: block;
}

.status-card-label {
    font-size: 12px;
    color: #64748b;
    font-weight: 700;
}

.status-card-value {
    display: block;
    margin: 8px 0 4px;
    font-size: 26px;
}

.status-card-note {
    font-size: 11px;
    color: #64748b;
}

.content-grid {
    margin-top: 15px;
    display: grid;
    grid-template-columns: minmax(0, 1fr) 330px;
    gap: 15px;
    align-items: start;
}

.main-column,
.side-column {
    display: flex;
    flex-direction: column;
    gap: 15px;
}

.section-card {
    padding: 15px;
}

.section-heading h2 {
    margin: 0;
    font-size: 18px;
}

.section-heading p {
    margin: 5px 0 0;
    color: #64748b;
    font-size: 12px;
}

.safety-note {
    display: block;
    margin-top: 8px;
    color: #64748b;
    font-size: 11px;
    line-height: 1.5;
}

.event-list {
    margin-top: 14px;
    display: flex;
    flex-direction: column;
    gap: 10px;
}

.event-card {
    padding: 12px;
    border: 1px solid #d7dde7;
    border-radius: 8px;
    background: #f8fafc;
}

.event-card-header {
    display: flex;
    align-items: center;
    justify-content: space-between;
    gap: 10px;
    margin-bottom: 10px;
}

.event-card-title {
    margin: 0;
    font-size: 13px;
}

.event-card-tools {
    display: flex;
    align-items: center;
    gap: 6px;
}

.event-delete {
    border: 0;
    background: #fee2e2;
    color: #b91c1c;
    border-radius: 5px;
    padding: 5px 8px;
}

.event-fields,
.condition-row,
.duration-row {
    display: grid;
    gap: 8px;
    align-items: end;
}

.schedule-fields {
    grid-template-columns: 150px minmax(170px, 1fr) 120px;
}

.condition-fields {
    grid-template-columns: 140px 90px 110px 140px 120px;
}

.second-condition-fields {
    grid-template-columns: 140px 90px 110px 90px 80px 140px;
}

.field-group {
    min-width: 0;
}

.field-group label {
    display: block;
    margin-bottom: 5px;
    color: #475569;
    font-size: 11px;
    font-weight: 700;
}

.condition-note {
    margin-top: 9px;
    color: #64748b;
    font-size: 11px;
}

.second-condition {
    margin-top: 10px;
    padding: 10px;
    border: 1px dashed #cbd5e1;
    border-radius: 7px;
    background: #fff;
}

.second-condition-head {
    display: flex;
    align-items: center;
    justify-content: space-between;
    gap: 8px;
    margin-bottom: 8px;
}

.inline-check {
    display: flex;
    align-items: center;
    gap: 6px;
    color: #475569;
    font-size: 11px;
    font-weight: 700;
}

#manual-duration {
    flex: 1;
}

#manual-unit {
    width: 120px;
}

.safety-note {
    margin-bottom: 0;
}

.switch-row {
    gap: 9px;
    margin-top: 14px;
    font-size: 13px;
    font-weight: 700;
}

.switch-row input {
    width: 18px;
    height: 18px;
}

.device-detail {
    justify-content: space-between;
    gap: 10px;
    padding: 9px 0;
    border-bottom: 1px solid #eef2f7;
    font-size: 12px;
}

.device-detail:last-child {
    border-bottom: 0;
}

.log {
    height: 240px;
    overflow-y: auto;
    padding: 10px;
    margin-top: 10px;
    border-radius: 7px;
    background: #0f172a;
    color: #dbeafe;
    font-family: Consolas, Monaco, monospace;
    font-size: 11px;
    white-space: pre-wrap;
}

.log-line {
    margin-bottom: 5px;
}

.empty-message {
    margin-top: 14px;
    color: #94a3b8;
    font-size: 12px;
}

.site-footer {
    margin-bottom: 25px;
    text-align: center;
    color: #64748b;
    font-size: 12px;
}

@media (max-width: 1100px) {
    .content-grid {
        grid-template-columns: 1fr;
    }

    .side-column {
        display: grid;
        grid-template-columns: repeat(2, minmax(0, 1fr));
    }
}

@media (max-width: 820px) {
    .status-grid {
        grid-template-columns: repeat(2, minmax(0, 1fr));
    }

    .schedule-fields,
    .condition-fields,
    .second-condition-fields {
        grid-template-columns: 1fr;
    }

    #device-address {
        width: 100%;
    }

    .side-column {
        grid-template-columns: 1fr;
    }
}

@media (max-width: 540px) {
    .header-content,
    .toolbar,
    .section-heading {
        align-items: stretch;
    }

    .header-content,
    .section-heading {
        flex-direction: column;
    }

    .status-grid {
        grid-template-columns: 1fr;
    }
}

)rawliteral";

const char APP_JS[] PROGMEM = R"rawliteral(
const MAX_DURATION_SECONDS = 1800
const STORAGE_KEY = 'esp32-smart-seedling-controller-v2'

const state = {
    baseUrl: 'http://192.168.4.1',
    connected: false,
    automationEnabled: false,
    manualDurationSeconds: 30,
    schedules: [],
    conditions: [],
    pollTimer: null
}

const elements = {
    address: document.querySelector('#device-address'),
    connectionDot: document.querySelector('#connection-dot'),
    connectionLabel: document.querySelector('#connection-label'),
    time: document.querySelector('#status-time'),
    clockNote: document.querySelector('#status-clock'),
    temperature: document.querySelector('#status-temperature'),
    humidity: document.querySelector('#status-humidity'),
    water: document.querySelector('#status-water'),
    waterTime: document.querySelector('#status-water-time'),
    automation: document.querySelector('#device-automation'),
    reason: document.querySelector('#device-reason'),
    remaining: document.querySelector('#device-remaining'),
    manualDuration: document.querySelector('#manual-duration'),
    manualUnit: document.querySelector('#manual-unit'),
    schedules: document.querySelector('#schedule-list'),
    scheduleEmpty: document.querySelector('#schedule-empty'),
    conditions: document.querySelector('#condition-list'),
    conditionEmpty: document.querySelector('#condition-empty'),
    log: document.querySelector('#log')
}

function log(message) {
    const line = document.createElement('div')
    line.className = 'log-line'
    line.textContent = `${new Date().toLocaleTimeString()}  ${message}`
    elements.log.append(line)
    elements.log.scrollTop = elements.log.scrollHeight
}

function setConnection(connected) {
    state.connected = connected
    elements.connectionDot.dataset.state = connected ? 'online' : 'offline'
    elements.connectionLabel.textContent = connected ? 'Connected' : 'Offline'
}

function baseUrl() {
    return elements.address.value.trim().replace(/\/+$/, '')
}

async function request(path, options = {}) {
    state.baseUrl = baseUrl()
    return fetch(`${state.baseUrl}${path}`, {
        cache: 'no-store',
        ...options
    })
}

function toSeconds(amount, unit) {
    const value = Math.max(0, Number(amount) || 0)
    if (unit === 'minutes') {
        return Math.round(value * 60)
    }
    if (unit === 'hours') {
        return Math.round(value * 3600)
    }
    return Math.round(value)
}

function fromSeconds(seconds) {
    const safe = Math.max(0, Number(seconds) || 0)
    if (safe % 3600 === 0 && safe >= 3600) {
        return { amount: safe / 3600, unit: 'hours' }
    }
    if (safe % 60 === 0 && safe >= 60) {
        return { amount: safe / 60, unit: 'minutes' }
    }
    return { amount: safe, unit: 'seconds' }
}

function createField(label, input) {
    const wrap = document.createElement('div')
    wrap.className = 'field-group'
    const text = document.createElement('label')
    text.textContent = label
    wrap.append(text, input)
    return wrap
}

function input(type, value, min, max, step = 1) {
    const element = document.createElement('input')
    element.className = 'text-input'
    element.type = type
    element.value = value
    if (min !== undefined) element.min = min
    if (max !== undefined) element.max = max
    if (step !== undefined) element.step = step
    return element
}

function select(options, value) {
    const element = document.createElement('select')
    element.className = 'select-input'
    options.forEach(option => {
        const item = document.createElement('option')
        item.value = option.value
        item.textContent = option.label
        if (option.value === value) item.selected = true
        element.append(item)
    })
    return element
}

function conditionSensor(value) {
    return select([
        { value: 'temperature', label: 'Temperature' },
        { value: 'humidity', label: 'Humidity' }
    ], value)
}

function conditionOperator(value) {
    return select([
        { value: '<', label: '<' },
        { value: '<=', label: '<=' },
        { value: '>', label: '>' },
        { value: '>=', label: '>=' },
        { value: '==', label: '=' },
        { value: '!=', label: '!=' }
    ], value)
}

function durationEditor(title, seconds) {
    const wrap = document.createElement('div')
    wrap.className = 'duration-row'
    const value = fromSeconds(seconds)
    const amount = input('number', value.amount, 1, 1800)
    const unit = select([
        { value: 'seconds', label: 'seconds' },
        { value: 'minutes', label: 'minutes' },
        { value: 'hours', label: 'hours' }
    ], value.unit)
    wrap.append(createField(title, amount), createField('Unit', unit))
    return { wrap, amount, unit }
}
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
void loop() {
    server.handleClient();
    readSensors();
    updateWatering();

    if (config.automationEnabled && !waterState) {
        processScheduledEvents();
        if (!waterState) processConditionEvents();
    }

    delay(1);
}

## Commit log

2026-09-04 9.4.2026: a bit stable version
    [ESP32_Smart_Seedling_Waterer.kicad_pcb]
2026-09-05 9.5.2026 rtc added
    [ESP32_Smart_Seedling_Waterer.kicad_pcb, ESP32_Smart_Seedling_Waterer.kicad_sch]
2026-09-06 9.7.2026 --remove unnecesssary
    [bom.csv, designators.csv, positions.csv]
